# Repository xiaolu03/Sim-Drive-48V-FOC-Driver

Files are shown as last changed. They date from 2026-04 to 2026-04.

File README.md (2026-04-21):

# 🏎️ Sim-Drive: High-Fidelity FOC Direct Drive Wheel Controller

## 📖 项目简介 (Project Overview)

**Sim-Drive** 是一套专为硬核模拟赛车（Sim Racing）量身打造的高保真、大扭矩直驱力回馈控制器系统。包含深度定制的 FOC 驱动主板、伺服电机选型策略以及高刚性机械连接方案。

本项目基于德国开发者 UltraWipf 的优秀开源项目 [OpenFFBoard](https://github.com/Ultrawipf/OpenFFBoard) 进行深度重构与改进。专为 **130ST / 110ST 等大扭矩工业伺服电机** 优化，打造了一款极具工业级鲁棒性（Robustness）的机电软硬一体化解决方案。

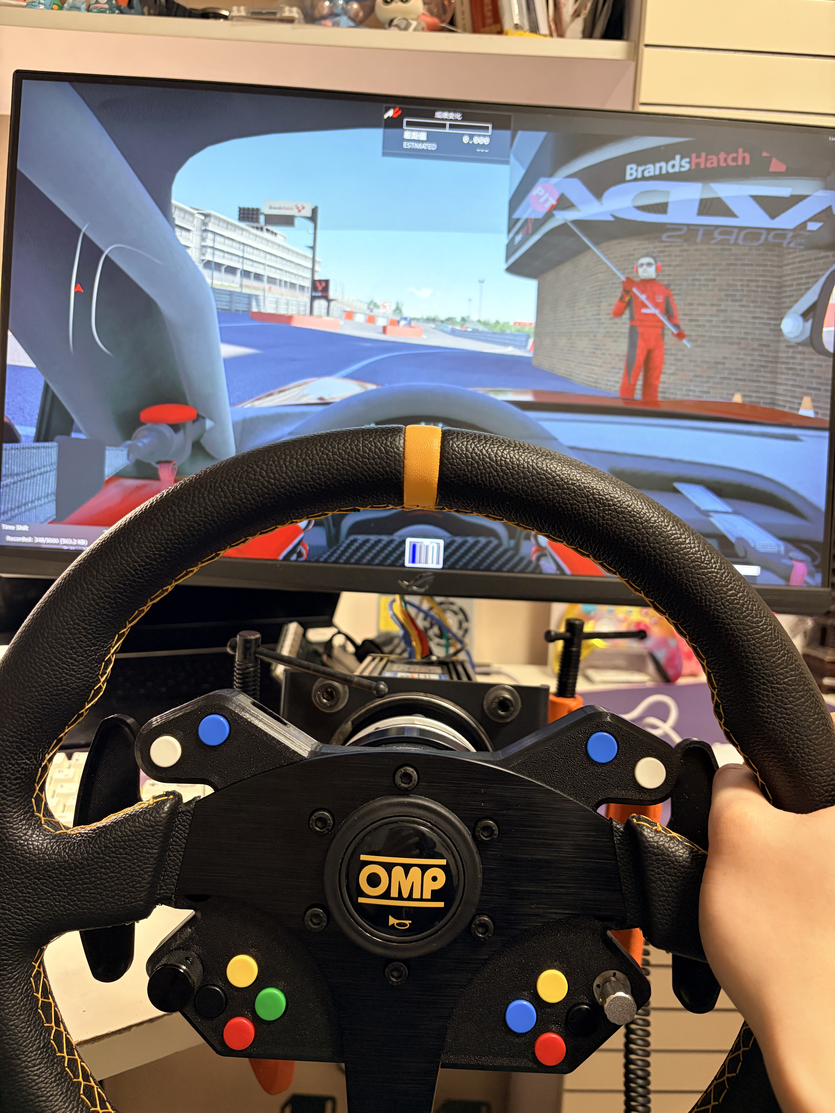
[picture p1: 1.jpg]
Sim-Drive 整机实装与游戏内测试图


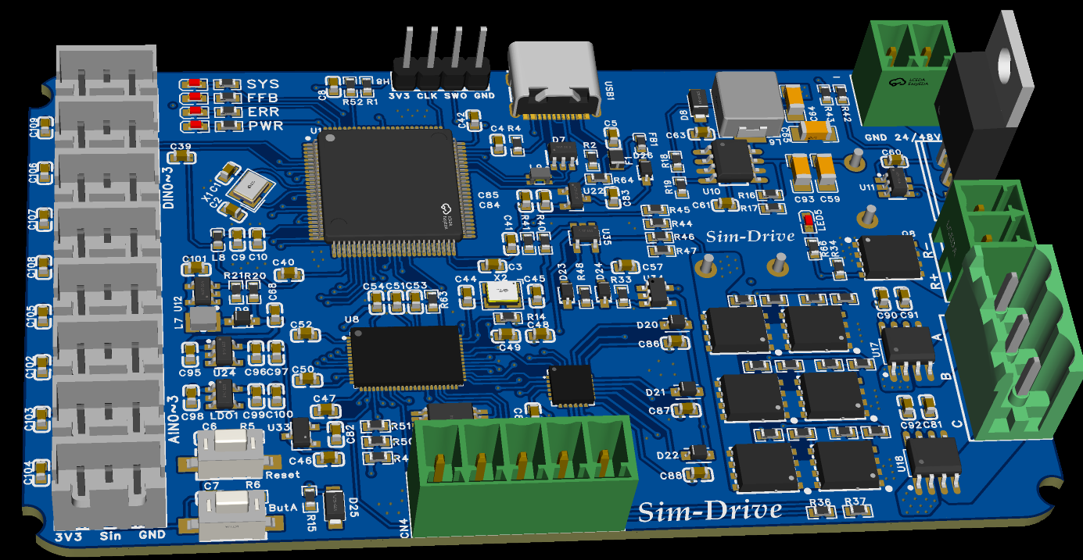
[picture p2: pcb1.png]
Sim-Drive 主板正面渲染图


---

## ⚡ 相比原版 OpenFFB 的核心进化 (Key Improvements vs. Original)

原版 OpenFFB 采用了“STM32 开发板 + 驱动扩展板”的分体堆叠架构，体积庞大且在极端工况下存在接口抗震性短板。本主板对其进行了**重度集成与工程化改造**：

1. **All-in-One 高集成度重构**：将原本分体的两块控制板融为一体。大幅缩小 PCB 体积，消除板间插针连接带来的接触电阻和寄生电感。
2. **去除冗余通道，专注伺服**：原版设计保留了对两相步进电机的支持。本板果断砍掉多余的第 4 条半桥通道，将布线资源和散热面积 100% 倾斜给 3 相 BLDC/PMSM 伺服电机。
3. **接口现代化与系统安全**：
   * 采用 **USB Type-C** 接口，并加入了原版缺失的 **USB 共模滤波 (Common Mode Choke) 与磁珠隔离**，根除大功率 PWM 切换导致的地弹掉线问题。
   * 集成 50W/100W 外置刹车电阻的**硬件级过压斩波器（Brake Chopper）**，并引入理想二极管防反接与隔离式电流采样，提供工业级安全防护。

---

## 🛠️ 深度硬件架构设计 (Detailed Hardware Architecture)

本板的设计拒绝任何“凑合能用”的妥协，在 EMC（电磁兼容）、PI（电源完整性）和 SI（信号完整性）上进行了极细致的推敲：

### 1. 极致的电源与安全冗余 (Power & Safety Redundancy)

* **0 压降防反接保护**：采用 `LM74700` 理想二极管控制器配合 `IRFB4110` (100V/120A) 大功率 MOS 管。即使在误接 48V 电源时也能瞬间关断保护后级，且正常工作时几乎无发热损耗。
* **高耐压 4 级电源树 (Power Tree)**：
  * **主降压**：采用 `MAX5035` 开关电源芯片（耐压高达 76V）将 48V 降至 5V，无惧电机抛负载（Load Dump）产生的电压尖峰。
  * **升压驱动**：通过 `AP3012` Boost 电路将 5V 升压至 12V-15V，专为栅极驱动器提供强劲的开启电压。
  * **数模隔离供电**：5V 降 3.3V 时，采用了**双 LDO 冗余架构**。`ME6211` 专供 STM32 数字逻辑，`SPX5205` 专供 ACS724 及运放的模拟参考端，从物理层面隔绝了数字高频噪声对 ADC 采样的污染。
* **独立硬件级过压刹车**：使用 `LMV321` 搭配 `SL27517` 驱动器，通过精密电阻分压，将**硬件强制刹车阈值精准卡在 63.7V**。当电机反电动势越过红线，无需 MCU 软件干预，硬件自动导通大功率 MOS 管，将能量泄放至外接的 50W/100W 黄金铝壳电阻，绝对保障母线电容不被击穿。

### 2. 驱动与电气隔离设计 (Drive & Galvanic Isolation)

* **分立式驱动架构**：采用 `TMC4671-LA` 硬件 FOC 协处理器，搭配 `FD6288Q` 三相栅极驱动器与 `WSD75100` (75V/100A) 功率 MOS 管。相比于高集成芯片，分立式设计分散了热源，提高了极端大扭矩工况下的热稳定性。
* **磁隔离电流采样**：摒弃了原版的电阻压降采样（Shunt），升级为 `ACS724-30AB` **霍尔效应电流传感器**。彻底实现了 48V 强电动力与 3.3V 弱电逻辑的**电气隔离 (Galvanic Isolation)**，杜绝了功率管击穿导致 MCU 连带烧毁的灾难。

### 3. EMC 专项抗干扰加固 (EMC & Ground Bounce Mitigation)

模拟赛车大功率 PWM 切换会产生严重的地弹（Ground Bounce）和共模干扰。本板在设计上打上了重重“补丁”：

* **USB 差分链路滤波**：在 Type-C 接口的 ESD 保护矩阵之后，针对性串联了 **`ACM2012-900-2P` 共模电感**。对有用的差分数据呈现 0Ω 阻抗，而对高频共模噪声提供 900Ω 的巨大阻抗墙，彻底根除高频脉冲导致的 USB 断联假死。
* **VBUS 射频净化**：在 USB 电源入口处串联高频磁珠（600Ω @ 100MHz），吸收线缆上的射频干扰。
* **编码器信号整形**：针对长线传输，在 5V TTL 编码器接口端加入了 `74LCX07` 缓冲器进行电平转换与施密特整形，确保 TMC4671 读取到的 A/B/Z 脉冲边沿陡峭且无毛刺。

### 4. PCB 布局与布线规范 (PCB Layout Rules)

* **叠层与阻抗控制**：严格采用 **4 层板 (Top-GND-Power-Bottom)** 结构。指定 `JLC04161H-7628` 压合参数，完美契合 8mil 线宽的 USB 差分对 **90Ω 阻抗匹配**。
* **完整地平面策略**：采用**统一地平面 (Solid Ground Plane)** 配合 **“逻辑分区布局”**（右侧高压动力区，左侧低压逻辑区）。避免了“切地”带来的跨分割大环形天线辐射。
* **大电流覆铜与散热**：在 DFN5x6 MOS 管区域进行大面积覆铜，并密布散热过孔 (Thermal Vias)，利用 PCB 铜皮作为天然散热器，使其在 15A 瞬态电流下即可维持被动散热。

### 5. 硬件文件快速入口 (Hardware Files)

* [MCU 原理图 PDF](./hardware/PDF_Schematic1_1_2026-02-19/SCH_Schematic1_1_1-MCU_2026-02-19.pdf)
* [Driver 原理图 PDF](./hardware/PDF_Schematic1_1_2026-02-19/SCH_Schematic1_1_2-DRIVER_2026-02-19.pdf)
* [Power 原理图 PDF](./hardware/PDF_Schematic1_1_2026-02-19/SCH_Schematic1_1_3-POWER_2026-02-19.pdf)
* [BOM](./hardware/BOM_v1.03_PCB1_103.xlsx)

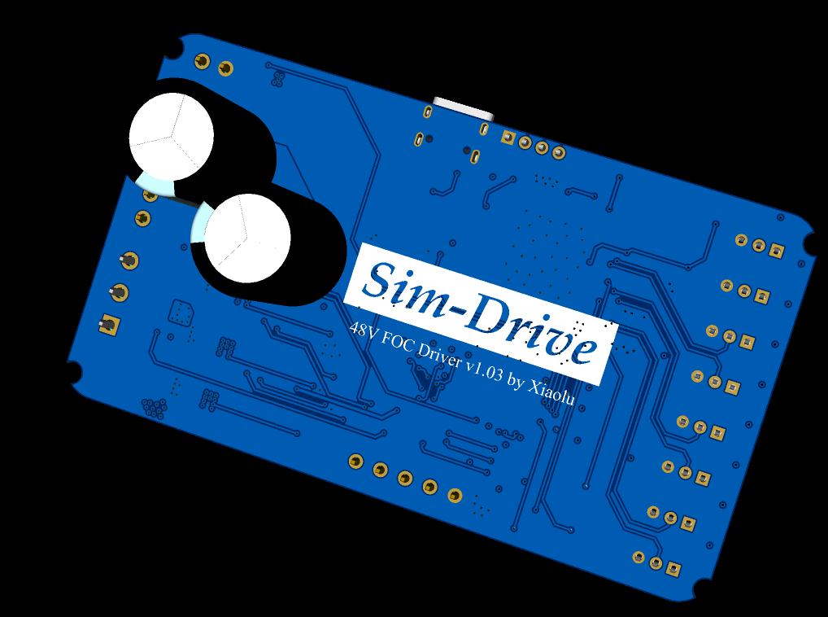
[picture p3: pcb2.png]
Sim-Drive 主板背面渲染图


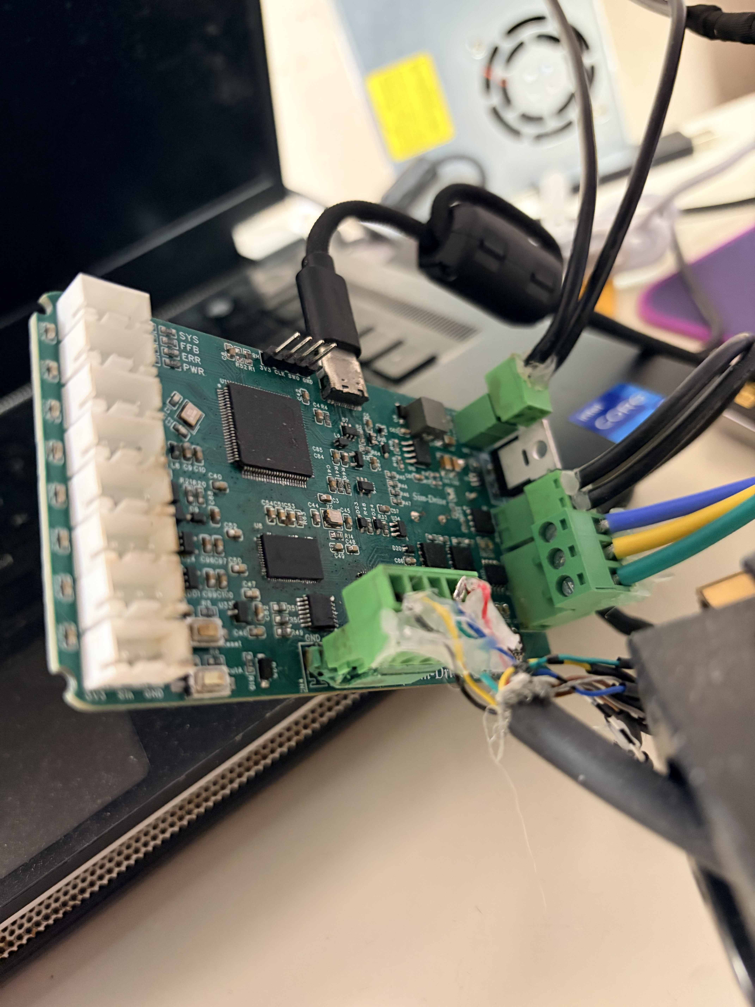
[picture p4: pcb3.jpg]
Sim-Drive 主板实物接线图


---

## 🚀 动力与传感系统选型 (Motor & Encoder Specifications)

本系统采用工业级交流伺服电机作为动力源，综合转动惯量与扭矩表现，选定 **110ST-M06030** 作为基准测试平台。

### 1. 伺服电机参数 (Servo Motor: 110ST-M06030)

* **额定/峰值扭矩**：6 N·m / ~18 N·m（配合 48V/15A 系统可爆发极强的瞬态动态响应）。
* **力矩系数 (Torque Constant)**：**1.0 N·m/A**（此处的 A 为总输入电流，可近似理解为同等总功率下的扭矩转化率）。
* **转动惯量 (Rotor Inertia)**：**7.6 kg/m² (* 10^-4)**。该惯量提供了模拟赛车所需的“真实机械阻尼感”，自带良好的物理低通滤波效应，手感厚重而不失细节。

### 2. 编码器接口定义 (Encoder: Tamagawa OIH 48-2500P8)

电机自带多摩川 (Tamagawa) 2500 线光电编码器（在 OpenFFB 固件中 CPR 配置为 10000）。通过主板板载的 `74LCX07` 缓冲器进行 5V 至 3.3V 的电平转换与施密特整形。

**物理接线线序（直连主板 5Pin 端子）：**

* 🟥 **红 (Red)**: `5V`（供电）
* 🟨 **黄 (Yellow)**: `Z`（Index 零位脉冲）
* 🟦 **蓝 (Blue)**: `B`（B 相脉冲）
* 🟩 **绿 (Green)**: `A`（A 相脉冲）
* ⬛ **黑 (Black)**: `G`（GND 地）

*(注：若电机原厂引出差分负极信号线 A-/B-/Z-，在单端接法下请做好绝缘包扎，悬空处理即可)*

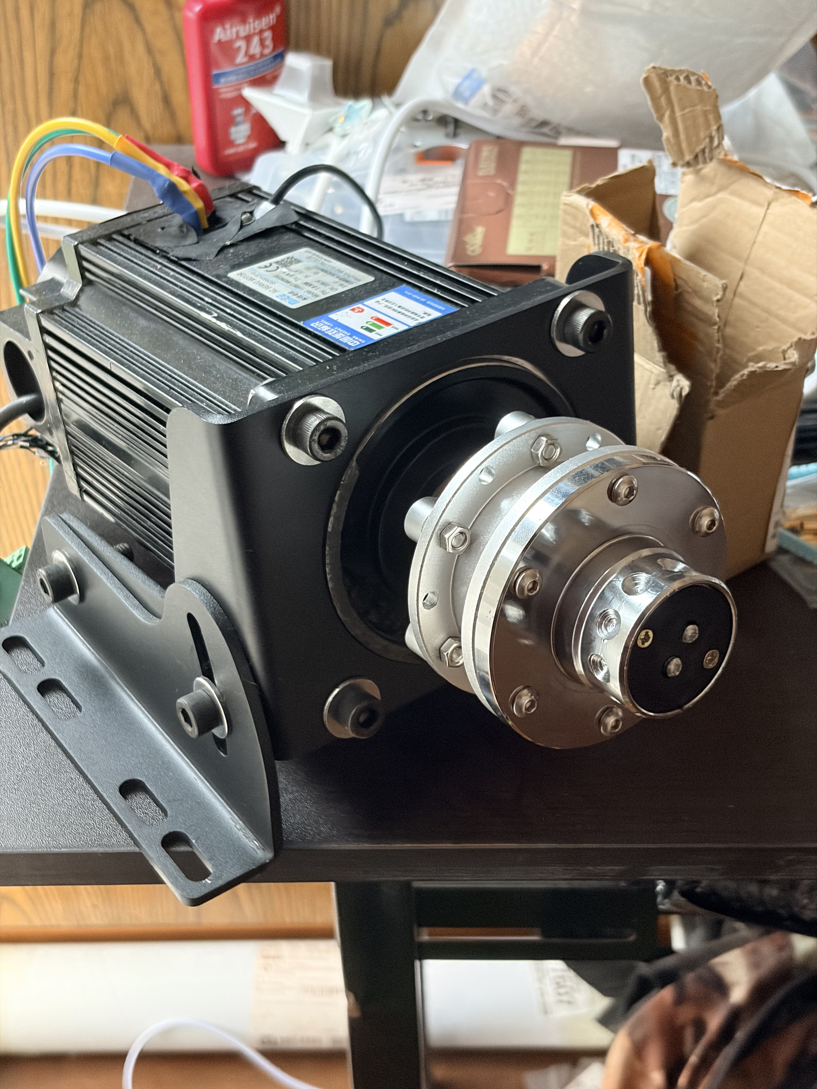
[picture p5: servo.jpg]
110ST 伺服电机与机械支架实装图


---

## ⚙️ 机械结构设计 (Mechanical Design)

本项目的机械部分专为 **110ST 系列工业伺服电机** 设计。为了确保在高频大扭矩力回馈（FFB）下无结构形变、无共振、无虚位，核心连接件均采用 **工业级标准件 + 定制 CNC/厚板钣金** 的组合方案。

### 1. 核心动力连接：涨紧套 (Expansion Sleeve)

本项目摒弃了传统的键槽连接或顶丝连接，采用工业级双锥面涨紧套，实现真正的 360° 无间隙（Zero Backlash）硬核锁死。

* **选用型号**：**Z21-19x35**（或同规格 Z2 型）。
* **适配参数**：内径 19mm（适配 110ST 标准电机轴），外径 35mm。
* **装配逻辑**：定制的 CNC 法兰盘直接替代涨紧套的原装前压环。螺丝穿过法兰盘直接锁入涨紧套主体，实现法兰与电机轴的一体化。

### 2. 定制法兰盘 (Custom CNC Flange)

法兰盘是连接电机轴与快拆/方向盘的核心媒介，要求极高的同心度与刚性。

* **加工工艺**：**8.0mm 厚度，铝合金 6061-T6**，CNC 加工，表面喷砂氧化黑。
* **核心尺寸设计**：
  * **中心定位孔 (19.1mm)**：电机 19mm 轴刚好穿过此孔，利用电机轴做物理极限定心，同心度极高。
  * **涨紧套适配槽 (内向腰型孔)**：由于市面 Z21 涨紧套的螺丝分布圆直径（BCD）在 26mm~28mm 之间浮动，本设计采用了 **槽宽 6.2mm、内边缘距中心孔 1.5mm** 的高容错腰型槽设计，完美兼容各厂牌公差。
  * **外圈快拆孔 (70mm PCD)**：标准 6 × M5 通孔，完美适配市面 99% 的赛车快拆（如 D1 Spec、NRG 等）。

### 3. 可调式电机支架 (Adjustable Motor Mount)

为承受 18N·m 的瞬态冲击，支架放弃了通用型的大开槽设计，采用 **110ST 专用孔位 + 分体式扇形调节** 结构。

* **加工工艺**：**4.0mm 厚度，SPCC (碳钢/冷轧板)**，激光切割 + 冲压折弯，表面 **喷塑（粉末喷涂）哑光黑**。
* **结构特点**：
  * **前面板 (Motor Plate)**：中心 95.2mm 避让孔，完美嵌合 110 电机止口；4 × 9mm 圆孔（90x90mm 间距）死死锁住电机法兰。
  * **侧支撑板 (Side Brackets)**：左右分体 L 型设计，底部具有 **20mm 加宽折弯边**，方便桌面 C 形夹或铝型材固定。
  * **无极角度调节**：侧板上方配有 **8.3mm 弧形滑轨槽**，配合下方 8mm 支点孔，实现电机仰角的平滑调节。

### 🛒 机械五金件 BOM 表 (Hardware BOM)

> ⚠️ **强烈警告**：直驱系统震动剧烈，所有受力螺丝**必须使用 12.9 级高强度合金钢材质**，所有螺母**必须使用带尼龙圈的防松螺母**，绝不可用普通 304 不锈钢螺丝替代！

| 部位 | 规格说明 | 数量 | 备注 |
| :--- | :--- | :--- | :--- |
| **法兰 ↔ 涨紧套** | M4 × 30mm 圆柱头内六角 (12.9级) | 4 颗 | 长度需穿透 8mm 法兰并吃满涨紧套螺纹 |
| **法兰 ↔ 涨紧套** | M4 加大平垫片 (外径 12mm 左右) | 4 片 | **必备**。用于完美覆盖 6.2mm 腰型槽，分散压紧力 |
| **方向盘 ↔ 快拆 ↔ 法兰** | M5 × 30mm 沉头内六角 (12.9级) | 6 颗 | 长度视个人 Hub 外壳厚度而定 |
| **电机 ↔ 支架前面板** | M8 × 20mm 圆柱头内六角 (12.9级) | 4 颗 | 从法兰侧向电机侧对穿锁紧 |
| **支架前面板 ↔ 侧支撑** | M8 × 25mm 圆柱头内六角 (12.9级) | 4 颗 | 用于转轴和弧形滑轨的连接锁定 |
| **支架全局锁紧** | M8 尼龙防松螺母 | 8 颗 | 配合上述所有 M8 螺丝使用 |
| **支架全局锁紧** | M8 加大平垫片 (外径 20mm-24mm) | 12 片 | 保护喷塑漆面，压紧 8.3mm 弧形槽 |

### 🛠️ 装配特别注意事项 (Assembly Notes)

1. **法兰盘螺丝锁紧顺序**：在锁紧 Z21 涨紧套的 4 颗 M4 螺丝时，务必采用 **“交叉对角线”** 方式（1-3-2-4 顺序），每次仅推进 1/4 圈。由于采用了 19.1mm 中心孔套轴定心，只要均匀上紧，法兰盘即可达到极其完美的端面垂直度。
2. **螺纹胶的使用**：强烈建议在快拆连接的 M5 螺丝、以及部分不易拆卸部位涂抹少量 **243 蓝色螺纹胶**（可拆卸型），以抵御长期的高频 FFB 震动。
3. **支架组装公差**：由于 4mm SPCC 喷塑后会增加约 0.15mm 的双边漆厚，前面板塞入两侧支撑板时可能会略紧。这是预留的刚性过盈设计，利用 M8 螺丝和加大垫片强行夹紧后，整个支架将坚如磐石。

---

## 🔌 电子架构与外设接口 (Electronic Architecture & Interfaces)

* **PCB 叠层设计**：严格采用 4 层板 (Top-GND-Power-Bottom) 结构。指定 `JLC04161H-7628` 压合参数，契合 8mil 线宽的 USB 差分对 90Ω 阻抗匹配要求。
* **CN1 (Power)**: 48V DC 输入（推荐匹配明纬 LRS-600-48 电源）。
* **CN3 (Motor)**: U, V, W 三相动力输出。
* **CN5 (Brake)**: 泄放电阻接口（务必外接 50W 10Ω 铝壳电阻）。
* **CN4 (Encoder)**: 5Pin 接口（5V, GND, A, B, Z），适配工业伺服电机光电编码器。
* **DIN/AIN (Expansion)**: 预留多路数字/模拟通道，用于后期扩展方向盘拨片、按钮 Hub。

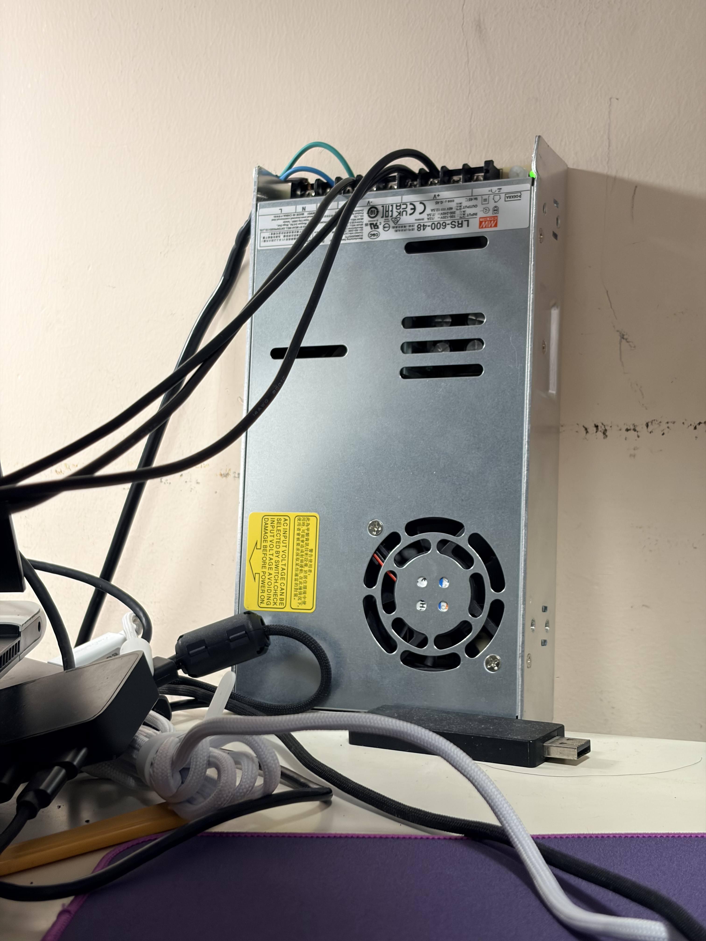
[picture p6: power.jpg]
48V 电源与整机布线实拍图


---

## 🐛 已知硬件勘误 (Hardware Errata & Known Issues)

**[Issue #01] Power Sequencing Boot Failure (电源时序导致启动失败)**

* **现象描述**：如果在未插入 USB 线（未给电脑供电）的情况下，直接单独插入 48V 主电源，主板可能会出现启动失败、电脑无法识别 USB 设备的情况。
* **根本原因分析 (Root Cause)**：由于采用了双 LDO 供电架构，USB 侧的 `VBUS` 检测逻辑与 48V 主降压回路之间存在上电时序（Power Sequencing）冲突。在无 USB VBUS 参考电平时，内部逻辑电平可能会处于不确定的闩锁（Latch-up）或未触发 STM32 内部 USB PHY 初始化复位的状态。
* **当前解决方案 (Workaround)**：**请始终先插入 USB Type-C 数据线连接电脑，然后再开启 48V 主电源。** 遵循此上电时序即可 100% 稳定运行。此问题将在下一版（Rev 1.1）的硬件重构中通过修改上电复位电容或 VBUS 唤醒逻辑进行修复。

---

## 🔬 系统级运作流程

本控制基座在物理与电气架构上是一个典型的高闭环带宽机电系统。其数据流、控制流与能量流的分工与流向如下：

```text
[ 上位机（游戏引擎） ]
           |
           |  （USB 2.0 全速 - HID 协议：力反馈效果与目标扭矩）
           v
 +-----------------------------------------------------------------------------------+
 | [ STM32F407 MCU ]（应用层）                                                        |
 |   - 解析 USB 报文，提取 FFB 矢量数据并计算瞬时目标力矩。                             |
 |   - 轮询处理周边设备 (DIN/AIN) 的状态，上传至上位机。                               |
 |         |                                                                         |
 |         |  （SPI 总线 - 2MHz 指令流）                                              |
 |         v                                                                         |
 | [ TMC4671-LA ASIC ]（硬件 FOC 引擎）                                               |
 |   - 硬件执行 Clarke/Park 与 iClarke/iPark 矩阵变换。                                |
 |   - 基于内置 PI 控制器维持电流环 (I_d = 0, I_q = 目标值)。                          |
 |         | （SVPWM 输出：25kHz）              ^ （ADC：相电流）                      |
 |         v                                   |                                     |
 | [ FD6288Q 栅极驱动器 ]             [ ACS724 霍尔电流传感器 ]                       |
 |   - 提供高低边死区控制与栅极升压。           - 提供磁隔离的相电流真实反馈。             |
 |         |                                   ^                                     |
 |         v （栅极驱动）                      |                                     |
 | [ WSD75100 三相 MOSFET 功率桥 ] -----------+                                     |
 |   - 将 48V 直流逆变为三相交流，驱动电机。                                           |
 +-----------------------------------------------------------------------------------+
           | （三相动力输出）                  ^ （ABZ 脉冲 -> 74LCX07 电平转换）
           v                                   |
 [ 110ST 伺服电机 ] ---------------------------+
           |
           v （剧烈反向受力时的反电动势）
 [ 过压刹车电路（LMV321 + SL27517） ] ---> [ 功率电阻（10Ω 50W） ]
```

### 运作流程解析

1. **信号接收与解算**  
   游戏引擎通过 DirectInput/XInput API 向硬件发送力反馈数据包。`STM32F407` 接收该数据包后，不直接参与底层的电机数学运算，而是作为协议网关，将换算后的目标扭矩通过高速 SPI 总线写入 `TMC4671` 的内部寄存器，实现算力的硬隔离。

2. **硬件级 FOC 闭环**  
   `TMC4671` 根据接收到的目标扭矩，结合当前从编码器读回的转子电角度（经 `74LCX07` 进行 5V 至 3.3V 缓冲转换），在硬件层执行 FOC 算法。芯片生成对应的 SVPWM（空间矢量脉宽调制）信号，交由 `FD6288Q` 栅极驱动器进行电平搬移与自举升压。

3. **功率逆变与反馈**  
   经过升压的 PWM 信号驱动由 6 颗 `WSD75100` 构成的三相逆变桥，将 48V 直流电转换为定子线圈所需的三相交流电。同时，串联在相位上的 `ACS724` 传感器实时侦测物理电流，将其转换为模拟电压信号送回 `TMC4671` 的 ADC 接口，完成微秒级的电流环闭环。

4. **主动过压防护**  
   当系统经历剧烈反向受力（如模拟撞车或急打方向）时，电机会进入发电机模式，产生反电动势并向母线倒灌。此时，完全独立于 MCU 的纯硬件比较器电路（由 `LMV321` 搭配 `SL27517` 构成）会实时监控分压网络。一旦母线电压突破 **63.7V** 阈值，比较器将瞬间越权导通专用的制动 MOSFET，将反冲能量导入外置的 10Ω 铝壳电阻进行热消耗，确保系统核心元器件的绝对安全。

---

*Designed & Documented by **xiaolu03*** | *Electronic Information Engineering Project*

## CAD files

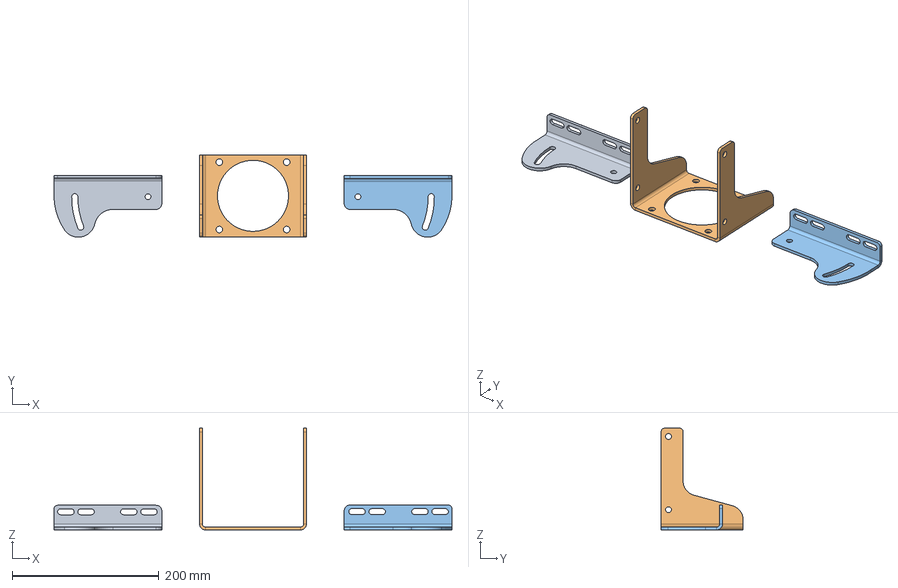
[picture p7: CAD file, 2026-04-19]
mechanical/110支架v2.step
543.3 x 112.4 x 139.0 mm

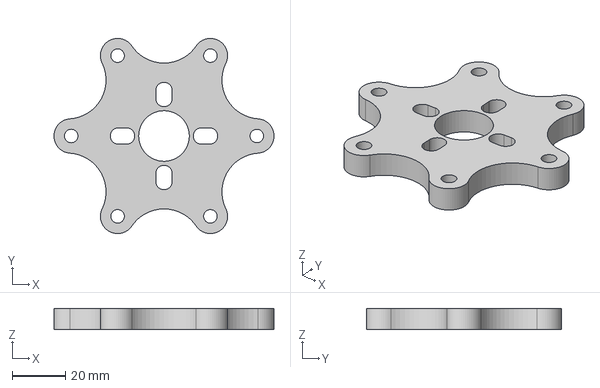
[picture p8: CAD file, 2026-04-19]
mechanical/110法兰v2.step
83.0 x 73.6 x 8.00 mm
